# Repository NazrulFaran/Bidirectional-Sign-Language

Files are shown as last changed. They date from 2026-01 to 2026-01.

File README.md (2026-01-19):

# Bidirectional Sign Language 🤟🔁🗣️

**Bidirectional Sign Language** is an interactive system that converts:

- **Hand signs → Speech** (via camera + hand pose model + TTS)
- **Voice → Robotic hand gestures** (via Vosk speech recognition + ESP32 + servos)

It uses a camera and deep learning on the PC side, and an ESP32 + PCA9685 + multiple servos + physical buttons on the hardware side.

---

## ✨ Features

- **Sign → Speech**
  - Real-time hand sign recognition using MediaPipe Hands + a custom TensorFlow model.
  - Each detected letter is spoken using Windows TTS (`winspeech`).
  - Builds up a word on-screen (with support for backspace and spacing).
  
- **Voice → Robotic Hand (Servo sequences)**
  - Press a physical button on the ESP32.
  - PC listens with a microphone using Vosk ASR (offline speech recognition).
  - Extracts **only letters (A–Z)**, truncates to **max 6 letters**.
  - Full-screen black display shows the **whole word** and the **current letter**.
  - Sends each letter one-by-one to ESP32, with **8 seconds delay per letter**.
  - ESP32 runs a custom servo sequence for each letter (A–Z, REL, etc.).

- **Hardware buttons on ESP32**
  - 4 buttons, all wired as `GPIO ↔ button ↔ GND` with `INPUT_PULLUP`.
  - Button mappings:
    - **BTN1 (GPIO 32)** → Quit the Python app (same as pressing `Q`).
    - **BTN2 (GPIO 33)** → Voice→Servo mode (record word and play on servos).
    - **BTN3 (GPIO 25)** → Clear current word in the Python app.
    - **BTN4 (GPIO 26)** → Speak currently detected word via TTS.

---

## 🧱 System Architecture

### PC Side (Python)

- **HandSignRecognizer** main class
  - Loads `improved_hand_model.h5` and `label_encoder.pickle`.
  - Uses **MediaPipe Hands** to extract 21 landmarks and normalize them.
  - Sends landmark vectors into the TensorFlow model to classify gesture (A–Z, `0` for backspace).
  - Uses **OpenCV** to show live video, bounding boxes, confidence bars, and the current word.
  - Uses **winspeech** to speak detected letters or full word.
  - Manages full-screen mode and UI overlays.

- **Vosk voice recognition**
  - Uses `vosk-model-small-en-us-0.15` (offline model, path configured via `VOSK_MODEL_PATH`).
  - Listens for a short window (e.g. 4 seconds) after the Voice+Servo button is pressed.
  - Converts recognized text to uppercase letters only, discards non-letters.
  - Truncates word to `MAX_VOICE_LETTERS = 6`.

- **Serial communication**
  - `pyserial` opens `COM7` at `115200` baud (configurable).
  - Receives button codes (`BTN1`, `BTN2`, `BTN3`, `BTN4`) from ESP32.
  - Sends single-character commands `A`–`Z` or `REL` to ESP32, one per servo gesture.

### ESP32 Side

- Hardware:
  - **ESP32** (with I2C pins 21 (SDA), 22 (SCL)).
  - **PCA9685** 16-channel servo driver (I2C address `0x40`).
  - Up to 14+ servos connected to PCA9685 channels (0–13).
  - 4 push buttons connected:
    - `GPIO32` (BTN1)
    - `GPIO33` (BTN2)
    - `GPIO25` (BTN3)
    - `GPIO26` (BTN4)
    - Each wired as: `GPIO ↔ button ↔ GND`.

- Firmware:
  - Uses `Adafruit_PWMServoDriver` to control servos via PWM.
  - Each letter `A`–`Z` has a dedicated `runSequenceX()` function.
  - `REL` and/or an initial `releasePosition()` sets base/idle posture.
  - A `checkButtons()` function:
    - Reads button states.
    - On `HIGH→LOW` transitions, prints `BTN1`, `BTN2`, `BTN3`, `BTN4` over Serial.

> The PC reads these lines and maps them to actions (Quit, Voice+Servo, Clear, Speak).

---

## 🛠️ Requirements

### Hardware

- ESP32 development board.
- PCA9685 16-channel servo driver.
- Multiple servos (e.g. 14 standard servos).
- 4 push buttons.
- Wires, breadboard or PCB.
- Stable 5V power supply for servos (with common ground to ESP32).
- USB cable from ESP32 to PC.
- Webcam.
- Microphone (for voice input).

### Software

- **OS:** Windows (required for `winspeech`).
- **Python:** 3.8+ (tested in Anaconda environment).
- **Libraries:** (see `requirements.txt`)
  - `opencv-python`
  - `mediapipe`
  - `numpy`
  - `tensorflow`
  - `winspeech`
  - `vosk`
  - `sounddevice`
  - `pyserial`

---

## 🚀 Getting Started

### 1. Clone repository

```bash
git clone https://github.com/<your-username>/Bidirectional-Sign-Language.git
cd Bidirectional-Sign-Language

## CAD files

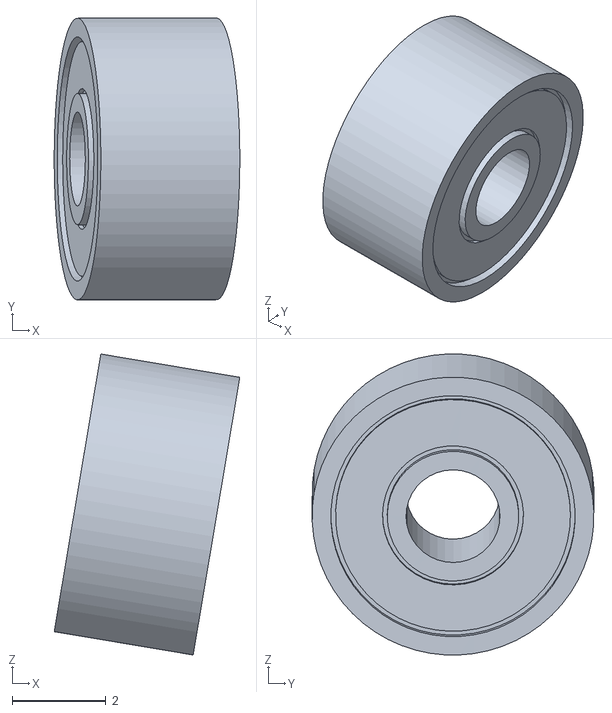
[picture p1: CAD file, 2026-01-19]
Designed File/System Assembly - Arm-1 Wrist_Joint_09-1 2x6x3-6.STL
3.95 x 5.99 x 6.41

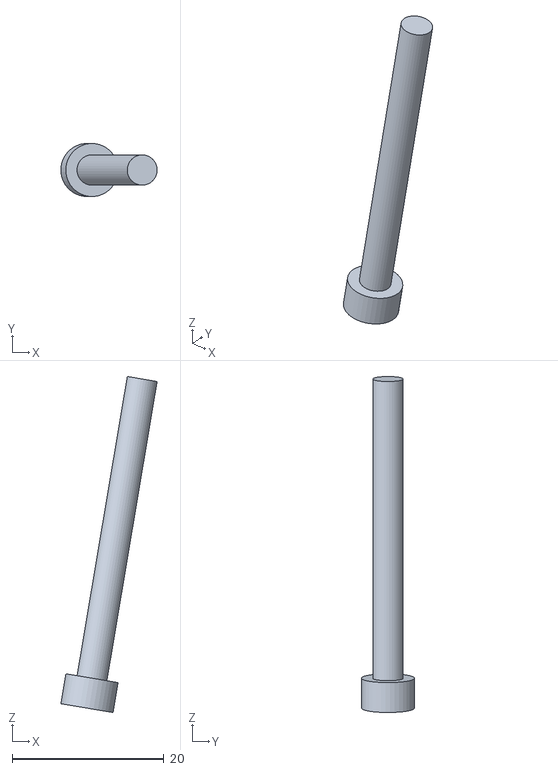
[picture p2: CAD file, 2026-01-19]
Designed File/System Assembly - Arm-1 Wrist_Joint_09-1 M4_Caphead_01-1.STL
12.7 x 6.98 x 44.3

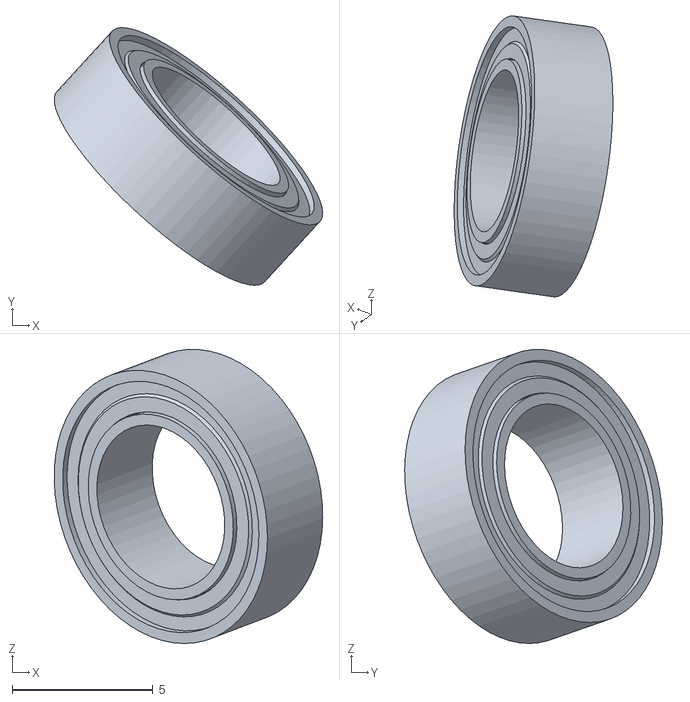
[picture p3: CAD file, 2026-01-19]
Designed File/System Assembly - Arm-1 Hand_05-1 T_THUMB_12-2 Thumb_Knuckle_05-1 6x10x3-4.STL
9.52 x 9.14 x 10.4

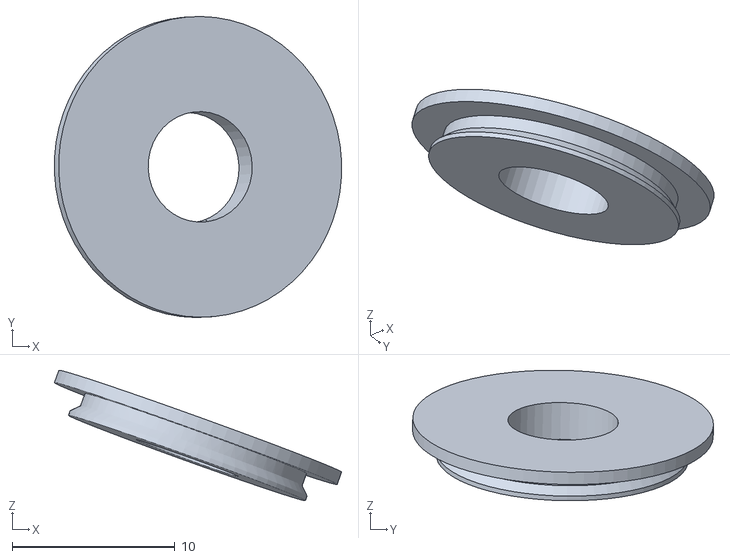
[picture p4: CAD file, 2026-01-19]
Designed File/System Assembly - Arm-1 Hand_05-1 Finger_Bearing_15-5 Tendon_Spool_01-6.STL
17.7 x 18.5 x 8.02

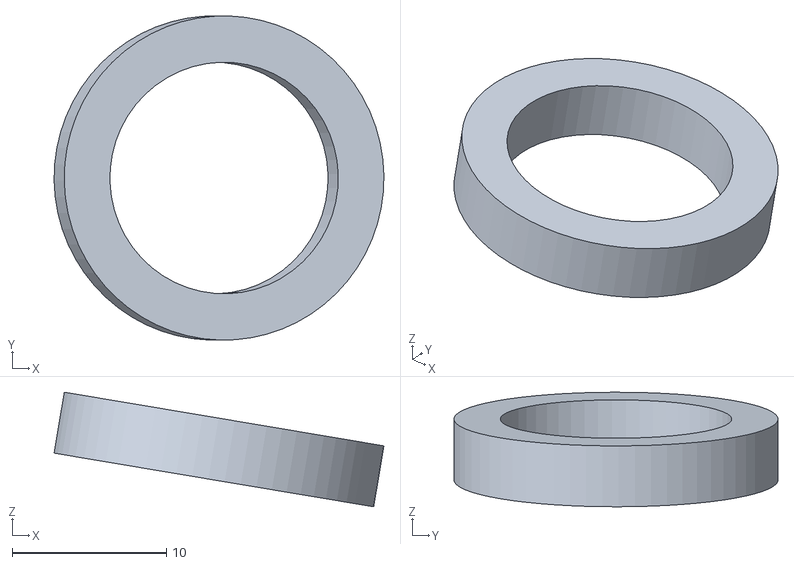
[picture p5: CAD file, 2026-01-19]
Designed File/System Assembly - Arm-1 Wrist_Joint_09-1 15x21x4-1.STL
21.4 x 21.0 x 7.42

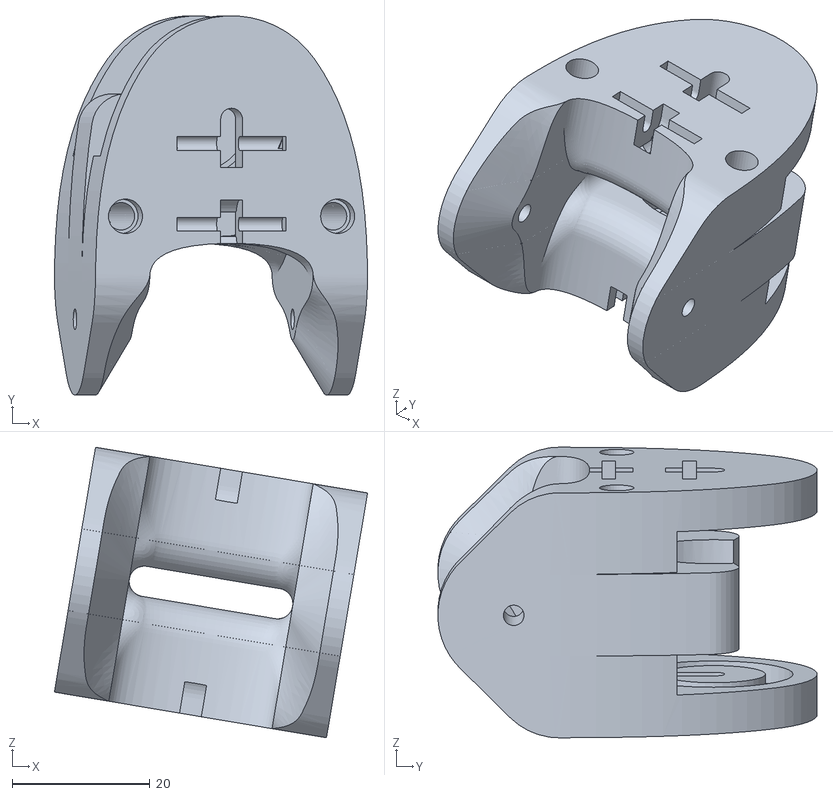
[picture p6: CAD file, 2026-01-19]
Designed File/System Assembly - Arm-1 Wrist_Joint_09-1 Distal_Wrist_09-1.STL
45.4 x 54.9 x 42.1

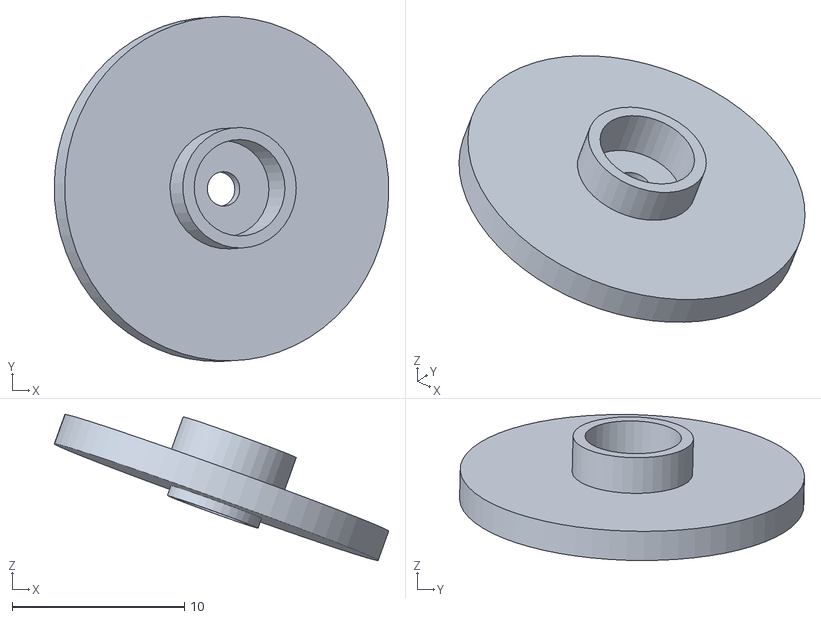
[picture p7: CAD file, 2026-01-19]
Designed File/System Assembly - Arm-1 Hand_05-1 Finger_Bearing_15-5 ES3302_Servo_Horn_Round_01-1.STL
19.4 x 20.0 x 8.48

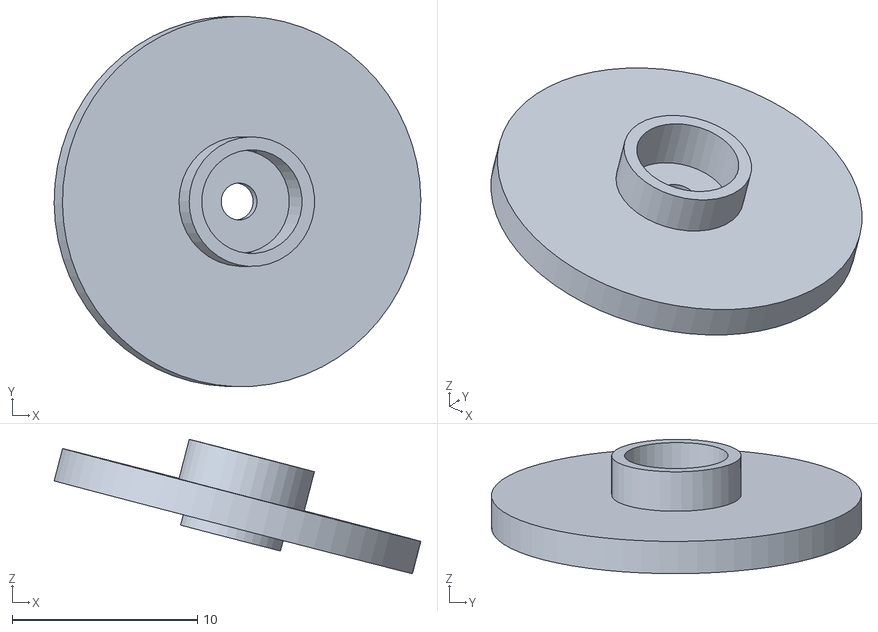
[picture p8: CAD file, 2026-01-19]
Designed File/System Assembly - Arm-1 Hand_05-1 Finger_Bearing_15-4 ES3302_Servo_Horn_Round_01-2.STL
19.8 x 20.0 x 7.26

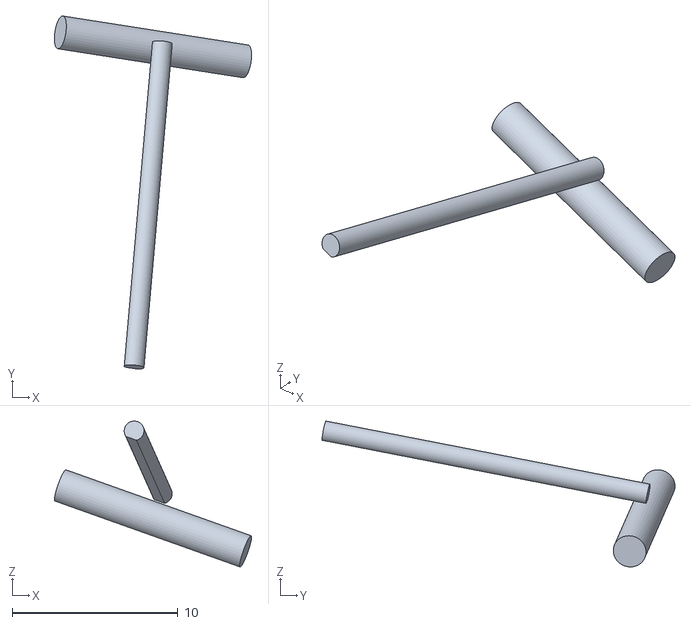
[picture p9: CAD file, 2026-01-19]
Designed File/System Assembly - Arm-1 Hand_05-1 Finger_Bearing_15-5 Test_2mm_01-2.STL
11.9 x 21.3 x 8.81

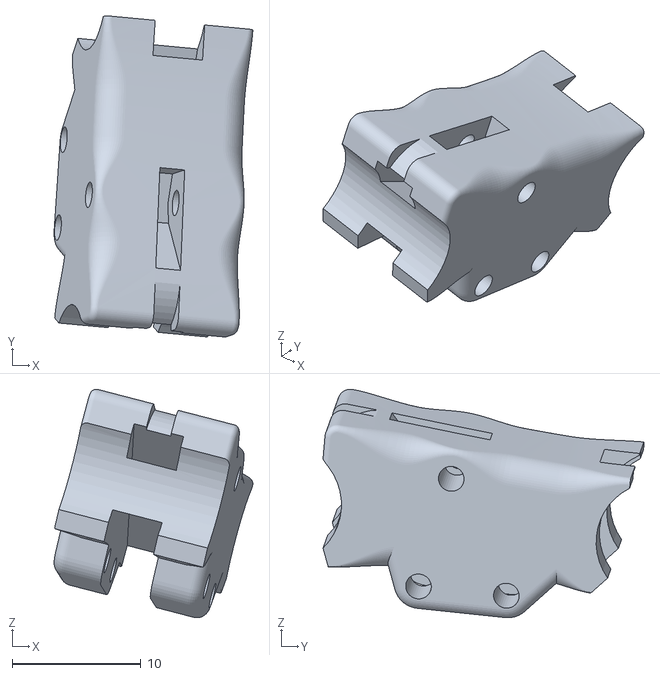
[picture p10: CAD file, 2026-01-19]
Designed File/System Assembly - Arm-1 Hand_05-1 Finger_Bearing_15-4 MLP_BEARING_15-1.STL
15.5 x 25.0 x 17.8

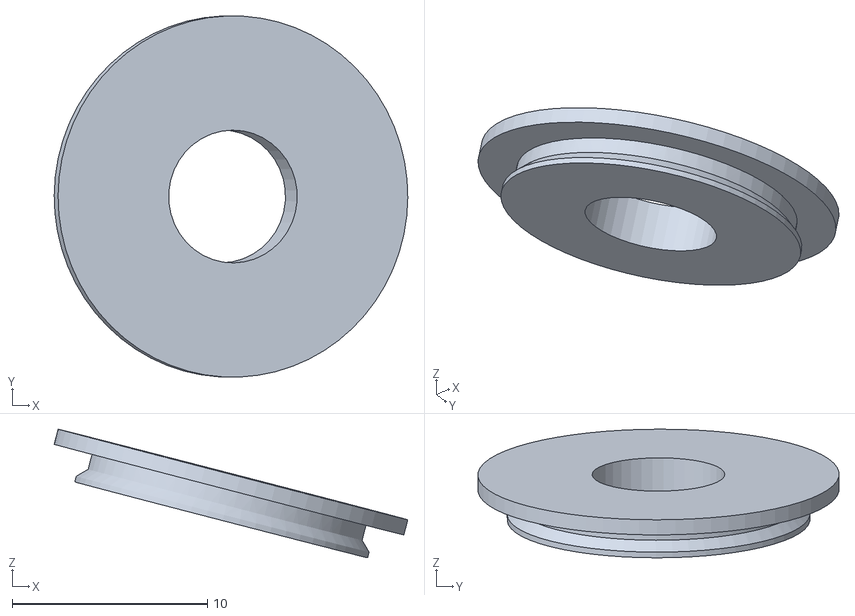
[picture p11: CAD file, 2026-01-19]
Designed File/System Assembly - Arm-1 Hand_05-1 Finger_Bearing_15-4 Tendon_Spool_01-6.STL
18.1 x 18.5 x 6.59

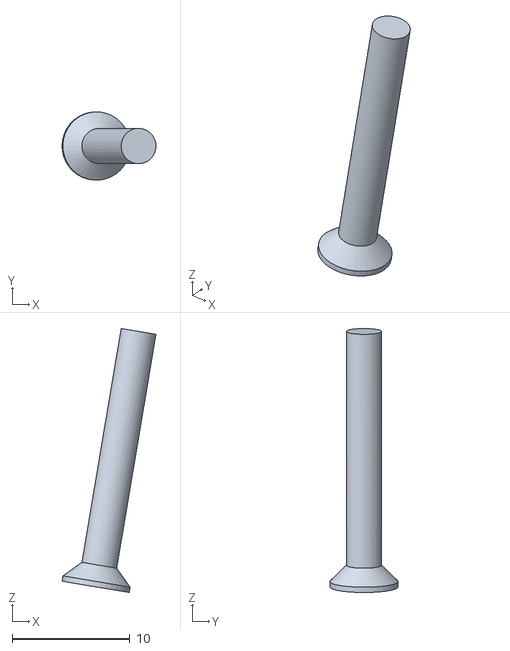
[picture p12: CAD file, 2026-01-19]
Designed File/System Assembly - Arm-1 Wrist_Joint_09-1 M3_CSunk_01-1.STL
7.98 x 5.79 x 22.4

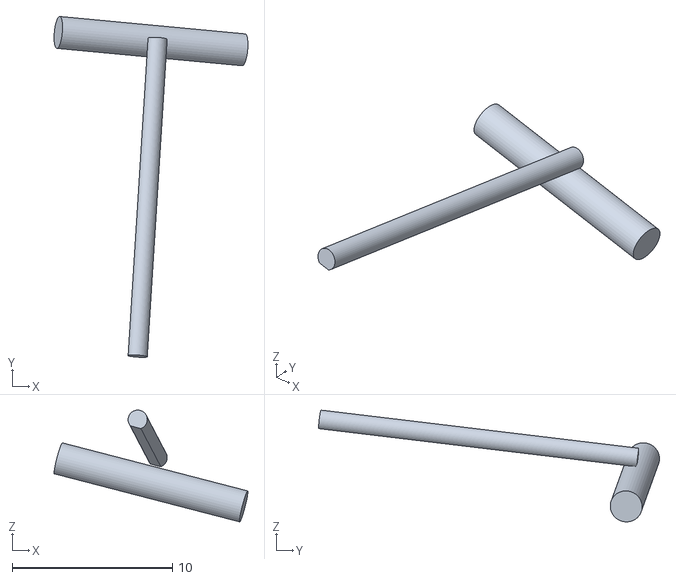
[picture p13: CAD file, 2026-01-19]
Designed File/System Assembly - Arm-1 Hand_05-1 Finger_Bearing_15-4 Test_2mm_01-2.STL
12.1 x 21.3 x 6.98

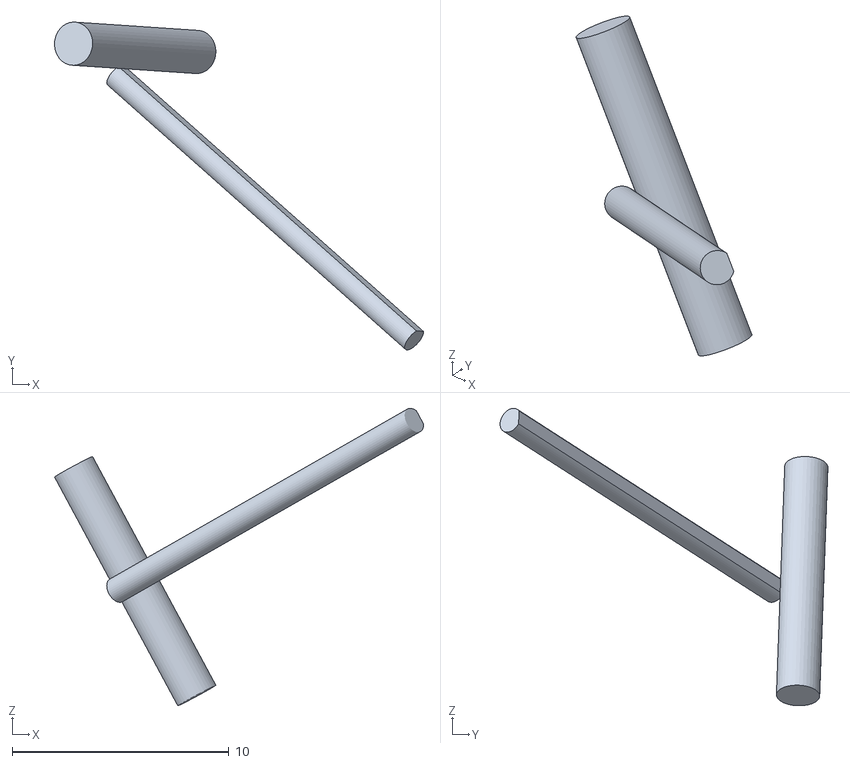
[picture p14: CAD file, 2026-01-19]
Designed File/System Assembly - Arm-1 Hand_05-1 T_THUMB_12-2 Test_2mm_01-3.STL
17.0 x 15.1 x 13.7

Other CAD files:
Designed File/System Assembly - Arm-1 Hand_05-1 T_THUMB_12-2 Thumb_Knuckle_05-1 6x10x3-5.STL
Designed File/System Assembly - Arm-1 Wrist_Joint_09-1 15x21x4-2.STL
Designed File/System Assembly - Arm-1 Hand_05-1 Finger_Bearing_15-5 6x10x3-3.STL
Designed File/System Assembly - Arm-1 Hand_05-1 T_THUMB_12-2 Thumb_Knuckle_05-1 CMCb_05-1.STL
Designed File/System Assembly - Arm-1 Forearm_18-1 18650_02-1.STL
Designed File/System Assembly - Arm-1 Forearm_18-1 18650_02-2.STL
Designed File/System Assembly - Arm-1 Forearm_18-1 55x72x9-2.STL
Designed File/System Assembly - Arm-1 Forearm_18-1 6x10x3-1.STL
Designed File/System Assembly - Arm-1 Forearm_18-1 ES3302_Servo_Horn_Round_01-10.STL
Designed File/System Assembly - Arm-1 Forearm_18-1 ES3302_Servo_Horn_Round_01-2.STL
Designed File/System Assembly - Arm-1 Forearm_18-1 ES3302_Servo_Horn_Round_01-3.STL
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

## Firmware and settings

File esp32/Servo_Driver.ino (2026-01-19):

#include <Wire.h>
#include <Adafruit_PWMServoDriver.h>

Adafruit_PWMServoDriver pwm = Adafruit_PWMServoDriver(0x40);

#define SERVO_MIN 150
#define SERVO_MAX 600

// ---- Button pins (change if you want) ----
const int BUTTON1_PIN = 32; // voice word + servo (BTN1)
const int BUTTON2_PIN = 33; // REL / home (BTN2)
const int BUTTON3_PIN = 25; // clear word in Python (BTN3)
const int BUTTON4_PIN = 26; // speak word in Python (BTN4)

// ---------- HELPER FUNCTIONS ----------

uint16_t angleToPulse(int angle) {
  angle = constrain(angle, 0, 180);
  return map(angle, 0, 180, SERVO_MIN, SERVO_MAX);
}

void setServoAngle(uint8_t channel, int angle) {
  if (channel > 15) return;           // we only have 16 channels (0–15)
  angle = constrain(angle, 0, 180);
  pwm.setPWM(channel, 0, angleToPulse(angle));
}

// ---------- YOUR CUSTOM FUNCTIONS ----------
void releasePosition() {
  // Example initial angles – CHANGE these to your needs:
  setServoAngle(0, 0); 
  setServoAngle(1, 150); 
  setServoAngle(2, 150); 
  setServoAngle(3, 0); 
  setServoAngle(4, 150); 
  setServoAngle(5, 150); 
  setServoAngle(6, 150); 
  setServoAngle(7, 0); 
  setServoAngle(8, 0); 
  setServoAngle(9, 150); 
  setServoAngle(10, 0); 
  setServoAngle(11, 0); 
  setServoAngle(12, 120); 
  setServoAngle(13, 70); 


  Serial.println("Release / home position set.");
}

// Sequence for command 'A'
void runSequenceA() {
  Serial.println("Running sequence A...");

  setServoAngle(2, 70);
  setServoAngle(5, 60);
  setServoAngle(8, 100);
  setServoAngle(11, 90);
  setServoAngle(12, 140);
  setServoAngle(13, 90);
  delay(500);
  setServoAngle(0, 110);
  setServoAngle(1, 50);
  setServoAngle(3, 120);
  setServoAngle(4, 30);
  setServoAngle(6, 20);
  setServoAngle(7, 120);
  setServoAngle(9, 30);
  setServoAngle(10, 110);
  delay(200);
  setServoAngle(13, 0);
  setServoAngle(12, 125);

  delay(3000);


  setServoAngle(13, 90);
  setServoAngle(12, 140);
  delay(200);
  setServoAngle(0, 0);
  setServoAngle(1, 150);
  setServoAngle(3, 0);
  setServoAngle(4, 150);
  setServoAngle(6, 150);
  setServoAngle(7, 0);
  setServoAngle(9, 150);
  setServoAngle(10, 0);
  delay(500);
  setServoAngle(13, 70);
  setServoAngle(2, 150);
  setServoAngle(5, 150);
  setServoAngle(8, 0);
  setServoAngle(11, 0);
  setServoAngle(13, 70);
  setServoAngle(12, 120);


  Serial.println("Sequence A done.");
}

// Sequence for command 'B'
void runSequenceB() {
  Serial.println("Running sequence B...");

  setServoAngle(12, 50);
  delay(100);
  setServoAngle(13, 0);

  delay(3000);

  setServoAngle(13, 70);
  delay(200);
  setServoAngle(12, 120);


  Serial.println("Sequence B done.");
}

// Sequence for command 'C'
void runSequenceC() {
  Serial.println("Running sequence C...");

  setServoAngle(2, 95);
  setServoAngle(5, 90);
  setServoAngle(8, 65);
  setServoAngle(11, 60);
  // delay(500);
  delay(200);
  setServoAngle(13, 40);
  setServoAngle(12, 110);

  delay(3000);


  setServoAngle(13, 70);
  setServoAngle(12, 120);
  setServoAngle(2, 150);
  setServoAngle(5, 150);
  setServoAngle(8, 0);
  setServoAngle(11, 0);


  Serial.println("Sequence C done.");
}

// Sequence for command 'D'
void runSequenceD() {
  Serial.println("Running sequence D...");

  setServoAngle(2, 70);
  setServoAngle(5, 60);
  setServoAngle(8, 100);
  setServoAngle(12, 140);
  setServoAngle(13, 80);

  delay(500);
  setServoAngle(0, 110);
  setServoAngle(1, 50);
  setServoAngle(3, 120);
  setServoAngle(4, 30);
  setServoAngle(6, 20);
  setServoAngle(7, 120);
  delay(100);
  setServoAngle(13, 40);
  delay(100);
  setServoAngle(12, 110);

  delay(3000);


  setServoAngle(12, 140);
  delay(100);
  setServoAngle(13, 80);
  delay(100);
  setServoAngle(0, 0);
  setServoAngle(1, 150);
  setServoAngle(3, 0);
  setServoAngle(4, 150);
  setServoAngle(6, 150);
  setServoAngle(7, 0);
  delay(500);
  setServoAngle(2, 150);
  setServoAngle(5, 150);
  setServoAngle(8, 0);
  setServoAngle(12, 120);
  setServoAngle(13, 70);

  Serial.println("Sequence D done.");
}


// Sequence for command 'E'
void runSequenceE() {
  Serial.println("Running sequence E...");

  setServoAngle(12, 0);
  setServoAngle(13, 0);
  delay(200);
  setServoAngle(13, 0);
  setServoAngle(2, 70);
  setServoAngle(5, 60);
  setServoAngle(8, 100);
  setServoAngle(11, 90);
  delay(400);
  setServoAngle(0, 40);
  setServoAngle(1, 110);
  setServoAngle(3, 45);
  setServoAngle(4, 105);
  setServoAngle(6, 110);
  setServoAngle(7, 45);
  setServoAngle(9, 105);
  setServoAngle(10, 40);

  delay(3000);

  setServoAngle(0, 0);
  setServoAngle(1, 150);
  setServoAngle(3, 0);
  setServoAngle(4, 150);
  setServoAngle(6, 150);
  setServoAngle(7, 0);
  setServoAngle(9, 150);
  setServoAngle(10, 0);
  delay(400);
  setServoAngle(2, 150);
  setServoAngle(5, 150);
  setServoAngle(8, 0);
  setServoAngle(11, 0);
  delay(200);
  setServoAngle(12, 120);
  setServoAngle(13, 70);


  Serial.println("Sequence e done.");
}

// Sequence for command 'F'
void runSequenceF() {
  Serial.println("Running sequence F...");

  
  setServoAngle(11, 90);
  setServoAngle(13, 90);
  delay(500);
  setServoAngle(9, 30);
  setServoAngle(10, 110);
  delay(200);
  setServoAngle(13, 40);
  setServoAngle(12, 95);

  delay(3000);


  setServoAngle(13, 90);
  setServoAngle(12, 120);
  delay(200);
  setServoAngle(9, 150);
  setServoAngle(10, 0);
  delay(500);
  setServoAngle(13, 70);
  setServoAngle(11, 0);


  Serial.println("Sequence F done.");
}

// Sequence for command 'G'
void runSequenceG() {
  Serial.println("Running sequence G...");

  setServoAngle(2, 70);
  setServoAngle(5, 60);
  setServoAngle(8, 100);
  setServoAngle(13, 100);
  setServoAngle(12, 140);
  delay(500);
  setServoAngle(0, 110);
  setServoAngle(1, 50);
  setServoAngle(3, 120);
  setServoAngle(4, 30);
  setServoAngle(6, 20);
  setServoAngle(7, 120);
  setServoAngle(10, 35);
  delay(200);
  setServoAngle(13, 0);


  delay(3000);


  setServoAngle(13, 100);
  setServoAngle(12, 140);
  delay(200); 
  setServoAngle(0, 0);
  setServoAngle(1, 150);
  setServoAngle(3, 0);
  setServoAngle(4, 150);
  setServoAngle(6, 150);
  setServoAngle(7, 0);
  setServoAngle(10, 0);
  delay(500);
  setServoAngle(13, 70);
  setServoAngle(12, 120);
  setServoAngle(2, 150);
  setServoAngle(5, 150);
  setServoAngle(8, 0);

  Serial.println("Sequence G done.");
}

// Sequence for command 'H'
void runSequenceH() {
  Serial.println("Running sequence H...");

  setServoAngle(2, 70);
  setServoAngle(5, 60);
  setServoAngle(13, 100);
  setServoAngle(12, 140);
  delay(500);
  setServoAngle(0, 110);
  setServoAngle(1, 50);
  setServoAngle(3, 120);
  setServoAngle(4, 30);
  setServoAngle(7, 30);
  setServoAngle(10, 35);
  delay(200);
  setServoAngle(13, 0);


  delay(3000);


  setServoAngle(13, 100);
  setServoAngle(12, 140);
  delay(200);
  setServoAngle(0, 0);
  setServoAngle(1, 150);
  setServoAngle(3, 0);
  setServoAngle(4, 150);
  setServoAngle(7, 0);
  setServoAngle(10, 0);
  delay(500);
  setServoAngle(13, 70);
  setServoAngle(12, 120);
  setServoAngle(2, 150);
  setServoAngle(5, 150);

  Serial.println("Sequence H done.");
}

// Sequence for command 'I'
void runSequenceI() {
  Serial.println("Running sequence I...");

  setServoAngle(5, 60);
  setServoAngle(8, 100);
  setServoAngle(11, 90);
  setServoAngle(13, 90);
  delay(500);
  setServoAngle(3, 120);
  setServoAngle(4, 30);
  setServoAngle(6, 20);
  setServoAngle(7, 120);
  setServoAngle(9, 30);
  setServoAngle(10, 110);
  delay(200);
  setServoAngle(13, 0);
  setServoAngle(12, 85);

  delay(3000);


  setServoAngle(13, 90);
  setServoAngle(12, 120);
  delay(200);
  setServoAngle(3, 0);
  setServoAngle(4, 150);
  setServoAngle(6, 150);
  setServoAngle(7, 0);
  setServoAngle(9, 150);
  setServoAngle(10, 0);
  delay(500);
  setServoAngle(13, 70);
  setServoAngle(5, 150);
  setServoAngle(8, 0);
  setServoAngle(11, 0);


  Serial.println("Sequence I done.");
}

// Sequence for command 'J'
void runSequenceJ() {
  Serial.println("Running sequence J...");

  setServoAngle(5, 60);
  setServoAngle(8, 100);
  setServoAngle(11, 90);
  setServoAngle(13, 90);
  delay(500);
  setServoAngle(0, 40);
  setServoAngle(3, 120);
  setServoAngle(4, 30);
  setServoAngle(6, 20);
  setServoAngle(7, 120);
  setServoAngle(9, 30);
  setServoAngle(10, 110);
  delay(200);
  setServoAngle(13, 0);
  setServoAngle(12, 85);

  delay(3000);


  setServoAngle(13, 90);
  setServoAngle(12, 120);
  delay(200);
  setServoAngle(0, 0);
  // setServoAngle(1, 135);
  setServoAngle(3, 0);
  setServoAngle(4, 150);
  setServoAngle(6, 150);
  setServoAngle(7, 0);
  setServoAngle(9, 150);
  setServoAngle(10, 0);
  // delay(200);
  // setServoAngle(1, 150);
  delay(500);
  setServoAngle(13, 70);
  setServoAngle(5, 150);
  setServoAngle(8, 0);
  setServoAngle(11, 0);


  Serial.println("Sequence J done.");
}

// Sequence for command 'K'
void runSequenceK() {
  Serial.println("Running sequence K...");

  setServoAngle(2, 70);
  setServoAngle(5, 60);
  setServoAngle(13, 100);
  delay(500);
  setServoAngle(0, 110);
  setServoAngle(1, 50);
  setServoAngle(3, 120);
  setServoAngle(4, 30);
  delay(200);
  setServoAngle(13, 0);


  delay(3000);


  setServoAngle(13, 100);
  delay(200);
  setServoAngle(0, 0);
  setServoAngle(1, 150);
  setServoAngle(3, 0);
  setServoAngle(4, 150);
  delay(500);
  setServoAngle(13, 70);
  setServoAngle(2, 150);
  setServoAngle(5, 150);

  Serial.println("Sequence K done.");
}

// Sequence for command 'L'
void runSequenceL() {
  Serial.println("Running sequence L...");

  setServoAngle(2, 70);
  setServoAngle(5, 60);
  setServoAngle(8, 100);
  setServoAngle(13, 130);
  delay(500);
  setServoAngle(0, 110);
  setServoAngle(1, 50);
  setServoAngle(3, 120);
  setServoAngle(4, 30);
  setServoAngle(6, 20);
  setServoAngle(7, 120);
  setServoAngle(12, 150);

  delay(3000);

  setServoAngle(12, 120);
  setServoAngle(0, 0);
  setServoAngle(1, 150);
  setServoAngle(3, 0);
  setServoAngle(4, 150);
  setServoAngle(6, 150);
  setServoAngle(7, 0);
  delay(500);
  setServoAngle(13, 70);
  setServoAngle(2, 150);
  setServoAngle(5, 150);
  setServoAngle(8, 0);

  Serial.println("Sequence L done.");
}

// Sequence for command 'M'
void runSequenceM() {
  Serial.println("Running sequence M...");

  setServoAngle(2, 70);
  delay(200);
  setServoAngle(0, 110);
  setServoAngle(1, 50);
  delay(100);
  setServoAngle(13, 0);
  setServoAngle(12, 30);
  delay(300);
  setServoAngle(5, 90);
  setServoAngle(8, 70);
  setServoAngle(11, 60);
  delay(400);
  setServoAngle(3, 90);
  setServoAngle(4, 60);
  setServoAngle(6, 50);
  setServoAngle(7, 90);
  setServoAngle(9, 60);
  setServoAngle(10, 80);

  delay(3000);

  setServoAngle(0, 0);
  setServoAngle(1, 150);
  setServoAngle(3, 0);
  setServoAngle(4, 150);
  setServoAngle(6, 150);
  setServoAngle(7, 0);
  setServoAngle(9, 150);
  setServoAngle(10, 0);
  delay(400);
  setServoAngle(2, 150);
  setServoAngle(5, 150);
  setServoAngle(8, 0);
  setServoAngle(11, 0);
  delay(200);
  setServoAngle(13, 70);
  setServoAngle(12, 120);


  Serial.println("Sequence M done.");
}


// Sequence for command 'N'
void runSequenceN() {
  Serial.println("Running sequence N...");

  setServoAngle(2, 70);
  setServoAngle(5, 60);
  delay(200);
  setServoAngle(0, 110);
  setServoAngle(1, 50);
  setServoAngle(3, 120);
  setServoAngle(4, 30);
  delay(100);
  setServoAngle(13, 0);
  setServoAngle(12, 50);
  delay(300);
  setServoAngle(8, 70);
  setServoAngle(11, 60);
  delay(400);
  setServoAngle(6, 50);
  setServoAngle(7, 90);
  setServoAngle(9, 60);
  setServoAngle(10, 80);

  delay(3000);

  setServoAngle(0, 0);
  setServoAngle(1, 150);
  setServoAngle(3, 0);
  setServoAngle(4, 150);
  setServoAngle(6, 150);
  setServoAngle(7, 0);
  setServoAngle(9, 150);
  setServoAngle(10, 0);
  delay(400);
  setServoAngle(2, 150);
  setServoAngle(5, 150);
  setServoAngle(8, 0);
  setServoAngle(11, 0);
  delay(200);
  setServoAngle(13, 70);
  setServoAngle(12, 120);


  Serial.println("Sequence N done.");
}

// Sequence for command 'O'
void runSequenceO() {
  Serial.println("Running sequence O...");

  setServoAngle(2, 95);
  setServoAngle(5, 90);
  setServoAngle(8, 65);
  setServoAngle(11, 60);
  delay(200);
  setServoAngle(13, 60);
  setServoAngle(12, 90);
  delay(400);
  setServoAngle(0, 35);
  setServoAngle(1, 115);
  setServoAngle(3, 45);
  setServoAngle(4, 105);
  setServoAngle(6, 100);
  setServoAngle(7, 50);
  setServoAngle(9, 105);
  setServoAngle(10, 45);


  delay(3000);

  setServoAngle(0, 0);
  setServoAngle(1, 150);
  setServoAngle(3, 0);
  setServoAngle(4, 150);
  setServoAngle(6, 150);
  setServoAngle(7, 0);
  setServoAngle(9, 150);
  setServoAngle(10, 0);
  delay(400);
  setServoAngle(13, 70);
  setServoAngle(12, 120);
  setServoAngle(2, 150);
  setServoAngle(5, 150);
  setServoAngle(8, 0);
  setServoAngle(11, 0);


  Serial.println("Sequence O done.");
}

// Sequence for command 'P'
void runSequenceP() {
  Serial.println("Running sequence P...");

  setServoAngle(2, 70);
  setServoAngle(5, 60);
  setServoAngle(8, 100);
  setServoAngle(12, 140);
  setServoAngle(13, 80);

  delay(500);
  setServoAngle(0, 110);
  setServoAngle(1, 50);
  setServoAngle(3, 120);
  setServoAngle(4, 30);
  setServoAngle(6, 20);
  setServoAngle(7, 120);
  setServoAngle(9, 115);
  setServoAngle(10, 35);
  delay(100);
  setServoAngle(13, 40);
  delay(100);
  setServoAngle(12, 110);

  delay(3000);


  setServoAngle(12, 140);
  delay(100);
  setServoAngle(13, 80);
  delay(100);
  setServoAngle(0, 0);
  setServoAngle(1, 150);
  setServoAngle(3, 0);
  setServoAngle(4, 150);
  setServoAngle(6, 150);
  setServoAngle(7, 0);
  setServoAngle(9, 150);
  setServoAngle(10, 0);
  delay(500);
  setServoAngle(2, 150);
  setServoAngle(5, 150);
  setServoAngle(8, 0);
  setServoAngle(12, 120);
  setServoAngle(13, 70);

  Serial.println("Sequence P done.");
}


// Sequence for command 'Q'
void runSequenceQ() {
  Serial.println("Running sequence Q...");

  setServoAngle(2, 70);
  setServoAngle(5, 60);
  setServoAngle(8, 100);
  setServoAngle(12, 140);
  setServoAngle(13, 80);

  delay(500);
  setServoAngle(0, 110);
  setServoAngle(1, 50);
  setServoAngle(3, 120);
  setServoAngle(4, 30);
  setServoAngle(6, 20);
  setServoAngle(7, 120);
  setServoAngle(9, 115);
  setServoAngle(10, 35);
  delay(100);
  setServoAngle(13, 50);
  delay(100);
  setServoAngle(12, 150);

  delay(3000);


  setServoAngle(0, 0);
  setServoAngle(1, 150);
  setServoAngle(3, 0);
  setServoAngle(4, 150);
  setServoAngle(6, 150);
  setServoAngle(7, 0);
  setServoAngle(9, 150);
  setServoAngle(10, 0);
  delay(500);
  setServoAngle(2, 150);
  setServoAngle(5, 150);
  setServoAngle(8, 0);
  setServoAngle(12, 120);
  setServoAngle(13, 70);

  Serial.println("Sequence Q done.");
}


// Sequence for command 'R'
void runSequenceR() {
  Serial.println("Running sequence R...");

  setServoAngle(2, 70);
  setServoAngle(5, 60);
  setServoAngle(12, 140);
  setServoAngle(13, 80);

  delay(500);
  setServoAngle(0, 110);
  setServoAngle(1, 50);
  setServoAngle(3, 120);
  setServoAngle(4, 30);
  setServoAngle(9, 130);
  setServoAngle(10, 40);
  delay(200);
  setServoAngle(6, 130);
  delay(100);
  setServoAngle(8, 30);
  setServoAngle(13, 40);
  delay(100);
  setServoAngle(12, 95);

  delay(3000);


  setServoAngle(12, 120);
  delay(100);
  setServoAngle(13, 70);
  setServoAngle(8, 0);
  delay(100);
  setServoAngle(6, 150);
  delay(200);
  setServoAngle(0, 0);
  setServoAngle(1, 150);
  setServoAngle(3, 0);
  setServoAngle(4, 150);
  setServoAngle(9, 150);
  setServoAngle(10, 0);
  delay(500);
  setServoAngle(2, 150);
  setServoAngle(5, 150);

  Serial.println("Sequence R done.");
}

// Sequence for command 'S'
void runSequenceS() {
  Serial.println("Running sequence S...");

  setServoAngle(2, 70);
  setServoAngle(5, 60);
  setServoAngle(8, 100);
  setServoAngle(11, 90);
  setServoAngle(13, 90);
  delay(500);
  setServoAngle(0, 110);
  setServoAngle(1, 50);
  setServoAngle(3, 120);
  setServoAngle(4, 30);
  setServoAngle(6, 20);
  setServoAngle(7, 120);
  setServoAngle(9, 30);
  setServoAngle(10, 110);
  delay(200);
  setServoAngle(13, 0);
  setServoAngle(12, 85);

  delay(3000);


  setServoAngle(13, 90);
  setServoAngle(12, 120);
  delay(200);
  setServoAngle(0, 0);
  setServoAngle(1, 150);
  setServoAngle(3, 0);
  setServoAngle(4, 150);
  setServoAngle(6, 150);
  setServoAngle(7, 0);
  setServoAngle(9, 150);
  setServoAngle(10, 0);
  delay(500);
  setServoAngle(13, 70);
  setServoAngle(2, 150);
  setServoAngle(5, 150);
  setServoAngle(8, 0);
  setServoAngle(11, 0);


  Serial.println("Sequence S done.");
}

// Sequence for command 'T'
void runSequenceT() {
  Serial.println("Running sequence T...");

  setServoAngle(2, 70);
  setServoAngle(5, 60);
  setServoAngle(8, 100);
  delay(200);
  setServoAngle(0, 110);
  setServoAngle(1, 50);
  setServoAngle(3, 120);
  setServoAngle(4, 30);
  setServoAngle(6, 20);
  setServoAngle(7, 120);
  delay(100);
  setServoAngle(13, 0);
  setServoAngle(12, 85);
  delay(300);
  setServoAngle(11, 60);
  delay(400);
  setServoAngle(9, 90);
  setServoAngle(10, 50);

  delay(3000);

  setServoAngle(9, 150);
  setServoAngle(10, 0);
  delay(200);
  setServoAngle(13, 70);
  setServoAngle(12, 120);
  delay(200);
  setServoAngle(0, 0);
  setServoAngle(1, 150);
  setServoAngle(3, 0);
  setServoAngle(4, 150);
  setServoAngle(6, 150);
  setServoAngle(7, 0);
  delay(400);
  setServoAngle(2, 150);
  setServoAngle(5, 150);
  setServoAngle(8, 0);
  setServoAngle(11, 0);



  Serial.println("Sequence T done.");
}

// Sequence for command 'U'
void runSequenceU() {
  Serial.println("Running sequence U...");

  setServoAngle(2, 70);
  setServoAngle(5, 60);
  setServoAngle(12, 140);
  setServoAngle(13, 80);

  delay(500);
  setServoAngle(0, 110);
  setServoAngle(1, 50);
  setServoAngle(3, 120);
  setServoAngle(4, 30);
  setServoAngle(6, 130);
  setServoAngle(9, 125);
  delay(100);
  setServoAngle(13, 40);
  delay(100);
  setServoAngle(12, 95);

  delay(3000);


  setServoAngle(12, 120);
  delay(100);
  setServoAngle(13, 70);
  delay(100);
  setServoAngle(0, 0);
  setServoAngle(1, 150);
  setServoAngle(3, 0);
  setServoAngle(4, 150);
  setServoAngle(6, 150);
  setServoAngle(9, 150);
  delay(500);
  setServoAngle(2, 150);
  setServoAngle(5, 150);
  setServoAngle(8, 0);

  Serial.println("Sequence U done.");
}
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
void loop() {
  // Check hardware buttons every loop
  checkButtons();

  // Handle incoming serial commands from Python
  if (Serial.available()) {
    String input = Serial.readStringUntil('\n');
    input.trim();

    if (input.length() == 0) return;

    if (input.equalsIgnoreCase("A")) {
      runSequenceA();
      return;
    } else if (input.equalsIgnoreCase("B")) {
      runSequenceB();
      return;
    } else if (input.equalsIgnoreCase("C")) {
      runSequenceC();
      return;
    } else if (input.equalsIgnoreCase("D")) {
      runSequenceD();
      return;
    } else if (input.equalsIgnoreCase("E")) {
      runSequenceE();
      return;
    } else if (input.equalsIgnoreCase("F")) {
      runSequenceF();
      return;
    } else if (input.equalsIgnoreCase("G")) {
      runSequenceG();
      return;
    } else if (input.equalsIgnoreCase("H")) {
      runSequenceH();
      return;
    } else if (input.equalsIgnoreCase("I")) {
      runSequenceI();
      return;
    } else if (input.equalsIgnoreCase("J")) {
      runSequenceJ();
      return;
    } else if (input.equalsIgnoreCase("K")) {
      runSequenceK();
      return;
    } else if (input.equalsIgnoreCase("L")) {
      runSequenceL();
      return;
    } else if (input.equalsIgnoreCase("M")) {
      runSequenceM();
      return;
    } else if (input.equalsIgnoreCase("N")) {
      runSequenceN();
      return;
    } else if (input.equalsIgnoreCase("O")) {
      runSequenceO();
      return;
    } else if (input.equalsIgnoreCase("P")) {
      runSequenceP();
      return;
    } else if (input.equalsIgnoreCase("Q")) {
      runSequenceQ();
      return;
    } else if (input.equalsIgnoreCase("R")) {
      runSequenceR();
      return;
    } else if (input.equalsIgnoreCase("S")) {
      runSequenceS();
      return;
    } else if (input.equalsIgnoreCase("T")) {
      runSequenceT();
      return;
    } else if (input.equalsIgnoreCase("U")) {
      runSequenceU();
      return;
    } else if (input.equalsIgnoreCase("V")) {
      runSequenceV();
      return;
    } else if (input.equalsIgnoreCase("W")) {
      runSequenceW();
      return;
    } else if (input.equalsIgnoreCase("X")) {
      runSequenceX();
      return;
    } else if (input.equalsIgnoreCase("Y")) {
      runSequenceY();
      return;
    } else if (input.equalsIgnoreCase("Z")) {
      runSequenceZ();
      return;
    } else if (input.equalsIgnoreCase("REL") || input.equalsIgnoreCase("RET")) {
      releasePosition();
      return;
    } else {
      // Try to interpret as: "channel angle"
      int channel, angle;
      if (sscanf(input.c_str(), "%d %d", &channel, &angle) == 2) {
        if (channel >= 0 && channel <= 15 && angle >= 0 && angle <= 180) {
          setServoAngle(channel, angle);
          Serial.print("Channel ");
          Serial.print(channel);
          Serial.print(" -> ");
          Serial.print(angle);
          Serial.println(" degrees");
        } else {
          Serial.println("Invalid channel or angle range.");
        }
      } else {
        Serial.print("Unknown command: ");
        Serial.println(input);
      }
    }
  }
}

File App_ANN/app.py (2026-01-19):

import pickle
import cv2
import mediapipe as mp
import numpy as np
import tensorflow as tf
import winspeech
from collections import deque
import threading
import time
import serial
import json
import queue
import sounddevice as sd
from vosk import Model, KaldiRecognizer
import sys

# ================== GLOBAL CONFIG ==================

# Vosk model
VOSK_MODEL_PATH = r"E:\Gesture_ANN\vosk-model-small-en-us-0.15"

# Serial ESP32
SERIAL_PORT = "COM7"
BAUD_RATE = 115200

# Audio (Vosk)
SAMPLE_RATE = 16000
BLOCK_DURATION_MS = 30  # ms

# Delay between letters when running voice→servo sequence
LETTER_INTERVAL_SEC = 8.0  # <<< changed to 8 seconds

# Max letters allowed from voice
MAX_VOICE_LETTERS = 6

# ===================================================


class HandSignRecognizer:
    def __init__(self):
        self.model = None
        self.label_encoder = None
        self.cap = None
        self.hands = None
        self.detected_words = []

        # Detection stability
        self.required_continuous_frames = 20
        self.confidence_threshold = 0.7
        self.frame_history = deque(maxlen=self.required_continuous_frames)
        self.last_spoken_char = None
        self.cooldown_frames = 20
        self.cooldown_counter = 0

        # TTS
        self.tts_lock = threading.Lock()
        self.is_speaking = False

        # Vosk / Serial
        self.vosk_model = None
        self.vosk_recognizer = None
        self.ser = None

        # Window name (for full screen)
        self.window_name = "✨ AI Hand Sign Recognition with TTS"

        # Main-loop running flag (for button1 = quit)
        self.running = True

        self.setup_tts()
        self.load_model()
        self.setup_camera()
        self.setup_vosk()
        self.setup_serial()

    # ============== TTS ==================
    def setup_tts(self):
        try:
            winspeech.say("Test")
        except Exception:
            pass

    def speak_text(self, text):
        try:
            winspeech.say(text)
        except Exception as e:
            print("TTS error:", e)

    # ============== Hand model ============
    def load_model(self):
        self.model = tf.keras.models.load_model('improved_hand_model.h5')
        label_dict = pickle.load(open('label_encoder.pickle', 'rb'))
        self.label_encoder = label_dict['label_encoder']
        print("✅ Hand model loaded")
        print("📊 Classes:", list(self.label_encoder.classes_))

    # ============== Camera / Mediapipe ============
    def setup_camera(self):
        # Try camera 0, then 1 if needed
        self.cap = cv2.VideoCapture(0)
        if not self.cap.isOpened():
            print("Camera 0 failed, trying camera 1...")
            self.cap = cv2.VideoCapture(1)

        if not self.cap.isOpened():
            print("❌ No camera available! Check connection.")
            self.cap = None
            return

        self.cap.set(cv2.CAP_PROP_FRAME_WIDTH, 1280)
        self.cap.set(cv2.CAP_PROP_FRAME_HEIGHT, 720)

        self.mp_hands = mp.solutions.hands
        self.mp_drawing = mp.solutions.drawing_utils
        self.mp_drawing_styles = mp.solutions.drawing_styles

        self.hands = self.mp_hands.Hands(
            static_image_mode=False,
            max_num_hands=2,
            min_detection_confidence=0.7,
            min_tracking_confidence=0.5
        )

    # ============== Vosk ==================
    def setup_vosk(self):
        print("Loading Vosk model... (this may take a few seconds)")
        try:
            self.vosk_model = Model(VOSK_MODEL_PATH)
            self.vosk_recognizer = KaldiRecognizer(self.vosk_model, SAMPLE_RATE)
            print("✅ Vosk model loaded")
        except Exception as e:
            print("⚠️ Failed to load Vosk model:", e)
            self.vosk_model = None
            self.vosk_recognizer = None

    # ============== Serial ==================
    def setup_serial(self):
        print(f"Opening serial port {SERIAL_PORT} at {BAUD_RATE} baud...")
        try:
            # small timeout so readline() won't block the GUI
            self.ser = serial.Serial(SERIAL_PORT, BAUD_RATE, timeout=0.01)
            time.sleep(2)
            print("✅ Serial connected.")
        except serial.SerialException as e:
            print(f"⚠️ Could not open serial port: {e}")
            self.ser = None

    def send_servo_command(self, cmd):
        """Send a single command (letter A–Z or 'REL') to the ESP32."""
        if self.ser is None:
            print("⚠️ No serial connection, cannot send servo command.")
            return
        try:
            send_str = cmd + "\n"
            self.ser.write(send_str.encode('utf-8'))
            print(f"--> SENT TO ESP32: {cmd}")
        except serial.SerialException as e:
            print("Serial write error:", e)

    # ============== Continuous detection ============
    def check_continuous_detection(self, char, confidence):
        if confidence >= self.confidence_threshold:
            self.frame_history.append(char)
        else:
            self.frame_history.append(None)

        if len(self.frame_history) < self.required_continuous_frames:
            return False

        return all(x == char and x is not None for x in self.frame_history)

    # ============== Frame processing =================
    def process_frame(self, frame):
        H, W = frame.shape[:2]

        if self.cooldown_counter > 0:
            self.cooldown_counter -= 1
            if self.cooldown_counter == 0:
                self.last_spoken_char = None

        side = max(H, W)
        frame_square = np.zeros((side, side, 3), dtype=np.uint8)
        frame_square[:H, :W] = frame
        frame_rgb = cv2.cvtColor(frame_square, cv2.COLOR_BGR2RGB)

        results = self.hands.process(frame_rgb)

        current_prediction = None
        current_confidence = 0
        detection_status = "Show Your Hand"

        if results and results.multi_hand_landmarks:
            for hand_landmarks in results.multi_hand_landmarks:

                self.mp_drawing.draw_landmarks(
                    frame_square,
                    hand_landmarks,
                    self.mp_hands.HAND_CONNECTIONS,
                    self.mp_drawing_styles.get_default_hand_landmarks_style(),
                    self.mp_drawing_styles.get_default_hand_connections_style()
                )

                x_ = [lm.x for lm in hand_landmarks.landmark]
                y_ = [lm.y for lm in hand_landmarks.landmark]

                data_aux = []
                for lm in hand_landmarks.landmark:
                    data_aux.append(lm.x - min(x_))
                    data_aux.append(lm.y - min(y_))

                if len(data_aux) == 42:
                    prediction = self.model.predict(np.array([data_aux]), verbose=0)
                    predicted_class = np.argmax(prediction)
                    confidence = np.max(prediction)
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
